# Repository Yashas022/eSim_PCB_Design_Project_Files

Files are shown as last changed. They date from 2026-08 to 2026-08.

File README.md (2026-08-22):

# DIY SpO₂ Monitoring PCB

A compact, educational pulse oximeter PCB based on the **Arduino Nano (ATmega328P)**. The board integrates an I²C pulse oximeter sensor module (MAX30100/MAX30102), an SSD1306 OLED display, 3-button navigation, power regulation, and an LED alarm indicator onto a single prototyping PCB designed in KiCad.

---

## Key Features
* **Controller:** Arduino Nano
* **Display:** 0.96" I²C SSD1306 OLED (128×64)
* **Sensor Interface:**  MAX30102 via I²C with interrupt support (`D2`)
* **User Input:** 3 tactile push buttons (`MODE`, `UP`, `DOWN`)
* **Alert System:** Visual LED threshold alarm (`D6`)
* **Design Tool:** KiCad EDA

---

## Repository Structure

```text
My_project/
└── SPo2/
    ├── hardware/
    │   ├── footprints/           # Custom footprint libraries (.pretty / .kicad_mod)
    │   ├── gerbers/              # Fabrication output files
    │   ├── spo2.kicad_pro        # KiCad project file
    │   ├── spo2.kicad_sch        # Schematic file
    │   └── spo2.kicad_pcb        # PCB layout file
    ├── docs/
    │   ├── schematic.pdf         # Schematic reference
    │   └── bom.csv               # Bill of materials
    └── README.md                 # Project documentation

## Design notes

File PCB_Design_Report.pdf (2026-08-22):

# PCB Design Report

## DIY SpO2 & Heart-Rate Monitor Arduino Nano-Based Biosensor Interface with OLED Display

Submitted for: FOSSEE eSim PCB Design Task Design Tool: eSim (KiCad-based schematic and PCB editor) Date:22 August 2026

PCB Design Report | DIY SpO2 & Heart-Rate Monitor | Page 1 of 8

## Table of Contents

1. Abstract
2. Introduction
3. Objectives
4. System Block Diagram
5. Component Description
6. Circuit Design and Working Principle
7. Schematic Diagram
8. Bill of Materials (BOM)
9. Arduino Pin Mapping
10. PCB Layout and Routing
11. Design Verification Checklist
12. Applications
13. Advantages and Limitations
14. Future Scope
15. Conclusion

PCB Design Report | DIY SpO2 & Heart-Rate Monitor | Page 2 of 8

## 1. Abstract

This report presents the design of a compact, Arduino Nano–based pulse oximeter and heart-rate monitoring device ("DIY SpO2"). The system uses a MAX30102 optical biosensor to measure blood-oxygen saturation (SpO2) and heart rate (BPM), an SSD1306 I2C OLED display for real-time readout, three push-buttons (Mode / Up / Down) for user interaction, and a status LED for alarm/activity indication. The complete design flow — schematic capture, component selection, bill of materials, pin mapping, PCB placement, and copper routing — was carried out in eSim (KiCad-based EDA tool) and is documented here along with the final routed board and its 3D rendered view. The design demonstrates key embedded-hardware concepts including I2C multi-device communication, digital input debouncing, mixed analog/digital PCB layout practices, and two-layer PCB routing.

## 2. Introduction

Pulse oximetry is a simple, non-invasive method of monitoring the oxygen saturation of a person's blood, along with heart rate, by shining light through (or reflecting light off) a peripheral part of the body such as a fingertip. With the increasing availability of low-cost integrated biosensor modules such as the MAX30102, it has become feasible for hobbyists, students, and embedded-systems learners to build their own pulse oximeter using an ordinary microcontroller board such as the Arduino Nano.

This project, referred to on the board silkscreen as "DIY SpO2", integrates the MAX30102 sensor, an SSD1306 OLED display, three tactile push-buttons, and a status LED around an Arduino Nano, and packages them onto a single custom PCB. The report covers the complete hardware design process, from the functional block diagram through to the final routed and rendered PCB, and is intended as project documentation for the FOSSEE eSim PCB Design Task.

## 3. Objectives

i. To design a schematic that interfaces a MAX30102 biosensor and an SSD1306 OLED display with an Arduino Nano over a shared I2C bus.

ii. To provide a simple three-button (Mode / Up / Down) user interface with hardware debouncing.

iii. To include a status/alarm LED for visual feedback.

iv. To lay out and route a compact, manufacturable 2-layer PCB in eSim, keeping the analog sensor isolated from digital switching noise.

v. To document the complete design — schematic, BOM, pin-mapping, and PCB routing — as a reference report.

## 4. System Block Diagram

At a system level, the board consists of five functional blocks connected to the Arduino Nano as shown below:

PCB Design Report | DIY SpO2 & Heart-Rate Monitor | Page 3 of 8
Block | Interface to Nano | Role
Power Supply (+5V/GND) | VIN / 5V / GND pins | Powers Nano, sensor, display, LED
MAX30102 Biosensor (U1) | I2C (A4/A5) + INT | Measures SpO2 and heart rate
SSD1306 OLED Display (U2) | I2C (A4/A5) | Displays readings / menu
Push-buttons (SW1-SW3) | Digital I/O (D2, D3, D4) | Mode select, Up, Down navigation
Status LED (D1) | Digital output (D12) | Alarm / activity indication

All peripheral communication (sensor + display) is multiplexed onto the same two-wire I2C bus, while the buttons and LED use dedicated single-purpose digital I/O lines.

## 5. Component Description

### 5.1 Arduino Nano (A1)

A compact ATmega328P-based development board acting as the system's main controller. It reads button inputs, communicates with the MAX30102 and SSD1306 over I2C, runs the SpO2/heart-rate calculation algorithm on the raw sensor samples, and drives the status LED and OLED output.

### 5.2 MAX30102 Biosensor (U1)

An integrated pulse-oximetry and heart-rate-monitor module containing red and IR LEDs, a photodetector, and onboard signal conditioning. It communicates over I2C (fixed address 0x57) and provides an interrupt (INT) output to notify the Arduino when new sample data is ready, avoiding the need for constant polling.

### 5.3 SSD1306 OLED Display (U2)

A 0.96-inch, 128x64 pixel monochrome OLED module driven over I2C (typical address 0x3C). It is used to display live BPM and SpO2 readings, along with any menu/mode information selected using the push-buttons.

### 5.4 Push-Buttons and Debounce Network (SW1-SW3, R1-R3, C1-C3)

Three tactile push-buttons, labelled on the silkscreen as "Down" (SW1), "Up" (SW2), and "Mode" (SW3), are each pulled up to +5V through a 1k resistor and filtered with a 100nF capacitor to ground. This RC network removes mechanical contact bounce so that the Arduino reads a single, clean logic transition per press.

### 5.5 Status LED (D1) and Current-Limiting Resistor (R4)

A single LED, labelled "alarm" on the silkscreen, is driven from Arduino pin D12 through a 1k current-limiting resistor (R4). It can be used to flag conditions such as low SpO2, sensor disconnection, or simply to indicate that a measurement is in progress.

## 6. Circuit Design and Working Principle

When the user places a finger on the MAX30102 sensor, its red and infrared LEDs illuminate the fingertip and the onboard photodetector measures the light reflected back. Because oxygenated and deoxygenated haemoglobin absorb red and infrared light differently, and blood volume in the fingertip pulses slightly with

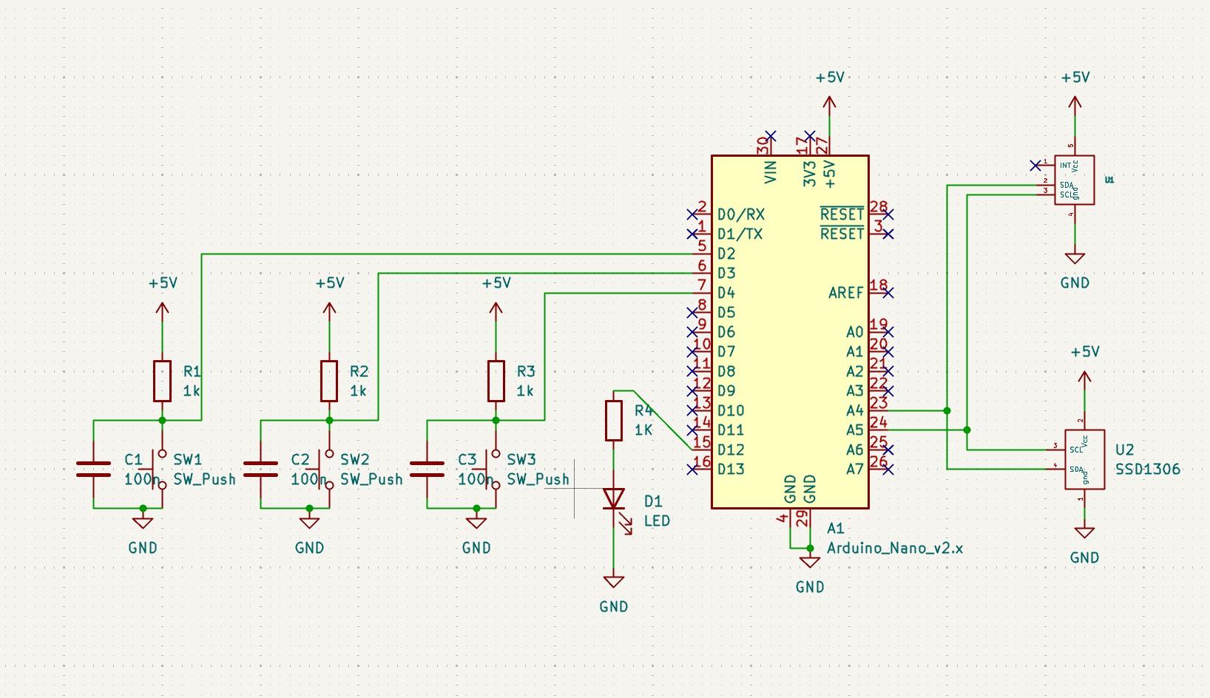
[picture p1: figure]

PCB Design Report | DIY SpO2 & Heart-Rate Monitor | Page 4 of 8

each heartbeat, the resulting waveform (the photoplethysmogram) can be processed to estimate both the heart rate (BPM) and blood-oxygen saturation (SpO2 %).

The MAX30102 buffers raw samples internally and raises its INT pin when a FIFO threshold is reached. The Arduino Nano services this interrupt, reads the samples over I2C, and runs a peak-detection / averaging algorithm to compute BPM and SpO2. These values are then written to the SSD1306 OLED over the same I2C bus for the user to read.

The three push-buttons let the user navigate a simple on-screen menu: SW3 ("Mode") cycles between display modes (e.g., live reading vs. history), while SW2 ("Up") and SW1 ("Down") scroll or adjust values within a mode. The status LED (D1) gives an at-a-glance indication, such as blinking with each detected pulse or lighting solidly for an alarm condition (e.g., SpO2 below a safe threshold).

Because U1 (MAX30102) and U2 (SSD1306) share the same SDA/SCL lines, both devices must use distinct I2C addresses. This is satisfied by design, as the MAX30102 is fixed at 0x57 and the SSD1306 module used here defaults to 0x3C — no address conflict or I2C multiplexer is required.

## 7. Schematic Diagram

Figure 1 shows the complete schematic capture of the design, produced in eSim.

Figure 1: Full circuit schematic (Arduino Nano, MAX30102, SSD1306, buttons, LED).

## 8. Bill of Materials (BOM)

Ref. Des. | Component | Value / Part | Qty | Function
A1 | Microcontroller module | Arduino Nano v2.x | 1 | Main controller
U1 | Biosensor module | MAX30102 | 1 | HR / SpO2 sensing (I2C)
U2 | OLED display | SSD1306, 0.96" I2C | 1 | Data / menu display
SW1-SW3 | Tactile push-button | SW_Push | 3 | User input (Down/Up/Mode)
R1-R3 | Resistor | 1k ohm | 3 | Button pull-up
R4 | Resistor | 1k ohm | 1 | LED current limit

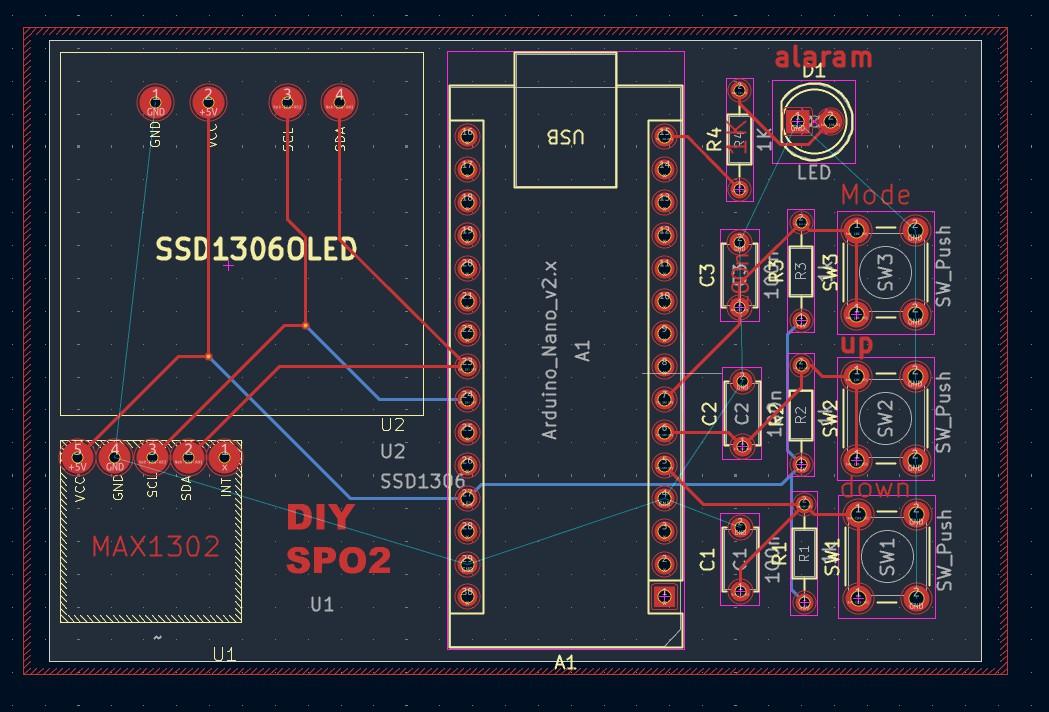
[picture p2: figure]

PCB Design Report | DIY SpO2 & Heart-Rate Monitor | Page 5 of 8

## 9. Arduino Pin Mapping

Signal | Arduino Pin | Connected To
Button - Down | D2 | SW1 (pull-up + debounce)
Button - Up | D3 | SW2 (pull-up + debounce)
Button - Mode | D4 | SW3 (pull-up + debounce)
LED drive (alarm) | D12 | D1 via R4
I2C data | A4 (SDA) | MAX30102 & SSD1306
I2C clock | A5 (SCL) | MAX30102 & SSD1306
Power | 5V / GND | All modules

## 10. PCB Layout and Routing

The board was placed and routed in eSim. Figure 2 shows the top-view copper routing (top layer in red, bottom layer in blue) and Figure 3 shows the 3D rendered view of the completed, assembled board.

Figure2:Top-viewPCB routing layout (red = top copper, blue = bottom copper).

D1 | LED | 5mm, generic | 1 | Alarm / status indicator
C1-C3 | Ceramic capacitor | 100 nF | 3 | Button debounce filter

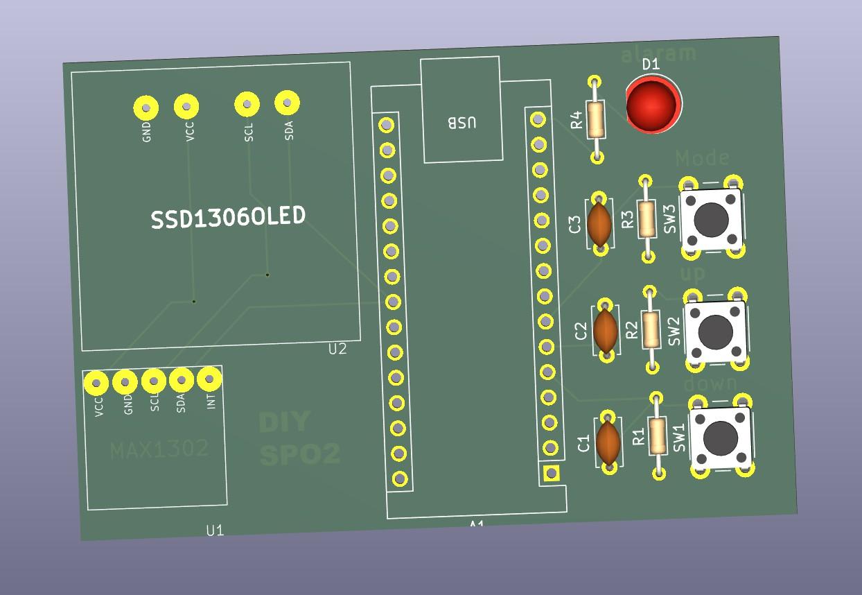
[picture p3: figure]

PCB Design Report | DIY SpO2 & Heart-Rate Monitor | Page 6 of 8

Figure 3: 3D rendered view of the assembled PCB.

### 10.1 Board Specifications

Layers: 2-layer PCB — top copper (red) and bottom copper (blue).

Board outline: rectangular, approx. 85mm x 55mm (estimated from layout proportions), edge-cut border shown by the red/white hatched outline.

Arduino Nano (A1) mounted via two long female headers running down the centre of the board, USB port oriented toward the top edge for easy programming access.

U2 (SSD1306) and U1 (MAX30102) connect via 4-pin and 5-pin headers respectively, on the left half of the board.

Silkscreen labels: "Mode" (SW3), "Up" (SW2), "Down" (SW1), "alarm" (D1/LED), and the project label "DIY SPO2".

### 10.2 Component Placement

Arduino Nano (A1) placed centrally, spanning the full height of the board, with header pins broken out on both sides for routing access.

U2 (SSD1306 OLED) placed top-left, isolated from the button/LED cluster for clear user visibility; GND/VCC/SCL/SDA pins routed directly to the Nano's I2C pins.

U1 (MAX30102) placed bottom-left, below the OLED, keeping the optical sensor away from the digital switching noise of the buttons and LED on the right side of the board.

Right-hand cluster: D1 (alarm LED) and R4 at the top, followed by three RC-debounced button groups (C3/R3/SW3 "Mode", C2/R2/SW2 "Up", C1/R1/SW1 "Down") stacked vertically, each within its own placement/courtyard outline.

USB connector footprint placed top-centre, above the Nano, keeping the programming port accessible at the board edge.

PCB Design Report | DIY SpO2 & Heart-Rate Monitor | Page 7 of 8

### 10.3 Routing Details

I2C bus (SDA/SCL): routed from the Nano's A4/A5 pins to both U1 and U2 using a mix of top (red) and bottom (blue) layer traces, with layer transitions at via points near the Nano header — visible as the crossing red/blue diagonal traces between the two modules.

Power distribution: +5V and GND (red traces) run from the Nano's power pins to the OLED and MAX30102 headers along the left side of the board.

Button and LED signal traces: red top-layer traces connect each SW/R/C debounce network to the corresponding Nano digital pin (D2/D3/D4) and D12 for the LED, kept short and direct within the right-hand cluster.

Thin cyan lines in the layout view are net/ratsnest reference guides for placement and do not represent unrouted copper.

Analog (MAX30102) and digital-switching (button/LED) traces are kept physically separated by routing them on opposite sides of the Arduino Nano footprint, reducing coupling between the sensitive optical front-end and noisy digital signals.

## 11. Design Verification Checklist

Item | Status
Schematic ERC (electrical rules check) passed | To be verified in eSim
All components assigned footprints | Complete
I2C addresses confirmed non-conflicting (0x57, 0x3C) | Confirmed by design
Component placement finalized | Complete
PCB routing (top + bottom copper) completed | Complete
DRC (design rule check) passed on PCB layout | To be verified in eSim
Gerber files generated for fabrication | Pending export from eSim

## 12. Applications

Personal, low-cost heart-rate and SpO2 self-monitoring device.

Educational demonstration of biosensor interfacing and I2C multi-device communication.

Base platform for wearable or bedside health-monitoring prototypes.

Reference design for students learning embedded systems and PCB design workflows.

## 13. Advantages and Limitations

### 13.1 Advantages

Low component count and low cost compared to commercial pulse oximeters.

Simple three-button interface requiring no external computer for operation.

Standard I2C interfacing makes the design easy to extend with additional sensors.

Compact 2-layer PCB keeps manufacturing simple and low-cost.

PCB Design Report | DIY SpO2 & Heart-Rate Monitor | Page 8 of 8

### 13.2 Limitations

Not a certified medical device; readings are indicative only and should not be used for clinical diagnosis.

Measurement accuracy is sensitive to finger placement, motion artefacts, and ambient light on the MAX30102 sensor.

No onboard battery management circuitry in the current design; the board is powered externally via +5V.

## 14. Future Scope

Add a battery and charging/power-management circuit for portable, wearable use.

Add Bluetooth/Wi-Fi connectivity (e.g., an ESP32 variant) for logging readings to a phone app.

Add data-logging to onboard flash/SD card for long-term trend tracking.

Enclose the sensor in a finger-clip housing to improve measurement repeatability.

## 15. Conclusion

This report has documented the complete design of a DIY SpO2 and heart-rate monitoring board built around an Arduino Nano, a MAX30102 biosensor, an SSD1306 OLED display, three push-buttons, and a status LED. The schematic, bill of materials, pin mapping, and final PCB layout and routing have all been presented. The design achieves its objectives of providing a functional, low-cost, and manufacturable pulse-oximeter board while demonstrating good PCB design practice, including I2C bus sharing, input debouncing, and separation of analog sensor circuitry from digital switching noise. The project is well suited to the FOSSEE eSim PCB Design Task as it exercises schematic capture, component placement, and multi-layer routing within a single, moderately-scoped, real-world design.

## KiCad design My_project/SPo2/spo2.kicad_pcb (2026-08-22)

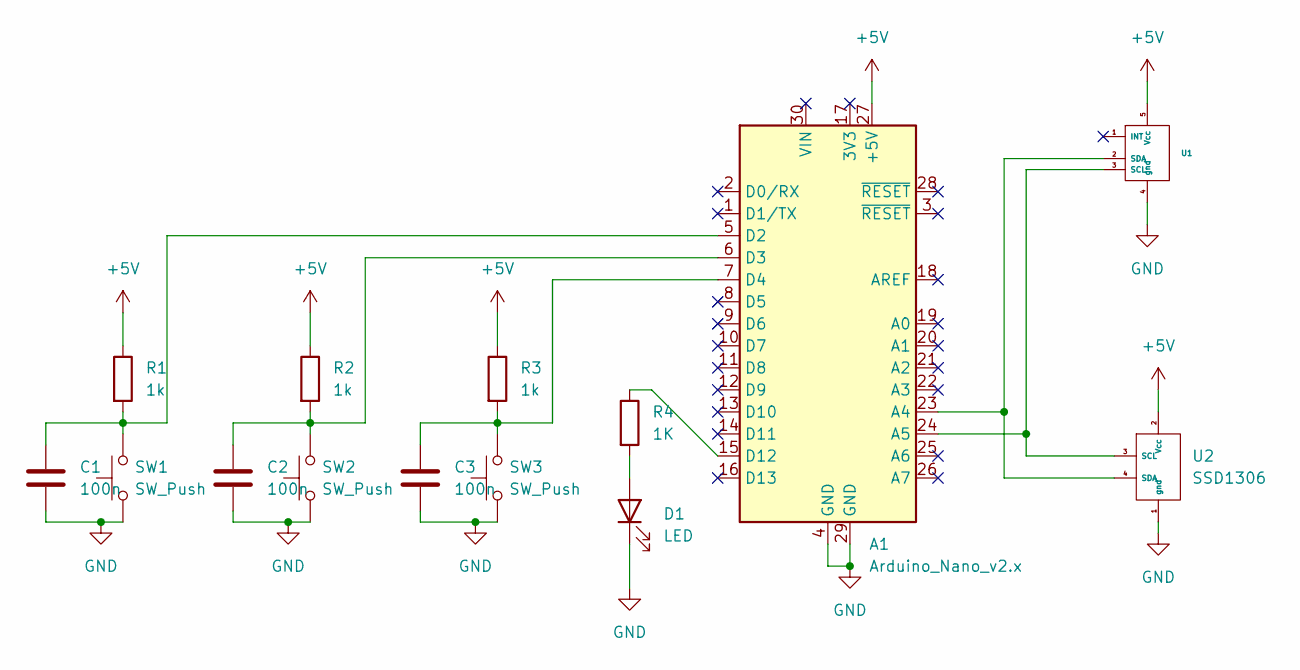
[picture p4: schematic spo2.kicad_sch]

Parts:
A1: Arduino_Nano_v2.x; Arduino_Nano
C1, C2, C3: 100n; C_Disc_D4.7mm_W2.5mm_P5.00mm
D1: LED; LED_D5.0mm
R1, R2, R3: 1k; R_Axial_DIN0204_L3.6mm_D1.6mm_P7.62mm_Horizontal
R4: 1K; R_Axial_DIN0204_L3.6mm_D1.6mm_P7.62mm_Horizontal
SW1, SW2, SW3: SW_Push; SW_PUSH_6mm
U1: MAX30102
U2: SSD1306

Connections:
+5V: A1.27 (+5V), R1.1, R2.1, R3.1, U1.5 (Vcc), U2.2 (Vcc)
GND: A1.4 (GND), A1.29 (GND), C1.2, C2.2, C3.2, D1.1 (K), SW1.2, SW2.2, SW3.2, U1.4 (gnd), U2.1 (gnd)
unnamed: A1.23 (A4), U1.2 (SDA), U2.4 (SDA)
unnamed: A1.24 (A5), U1.3 (SCL), U2.3 (SCL)
unnamed: A1.5 (D2), C1.1, R1.2, SW1.1
unnamed: A1.6 (D3), C2.1, R2.2, SW2.1
unnamed: A1.7 (D4), C3.1, R3.2, SW3.1
unnamed: A1.15 (D12), R4.1
unnamed: D1.2 (A), R4.2

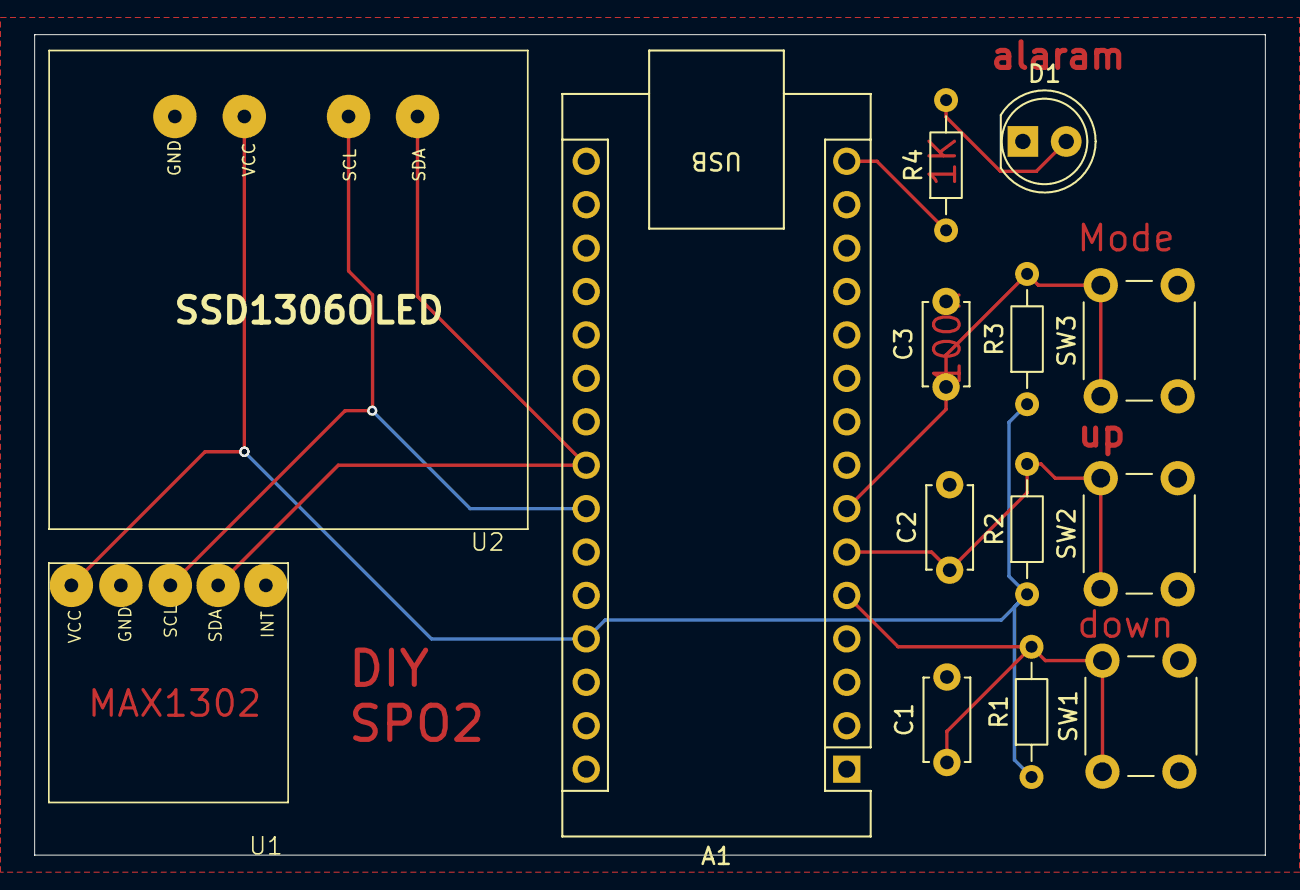
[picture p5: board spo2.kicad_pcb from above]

Board: 2 copper layers, 72.0 x 48.0 mm, 14 parts (0 on the bottom side), 9 nets.
